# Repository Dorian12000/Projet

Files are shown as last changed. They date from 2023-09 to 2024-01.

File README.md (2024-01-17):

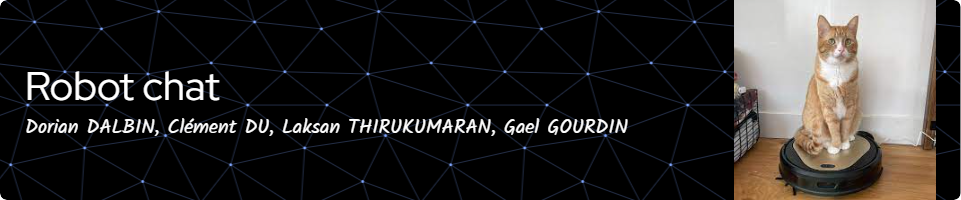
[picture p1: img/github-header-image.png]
robot chat


# Robot Chat et Souris

Ce projet consiste à créer un robot capable de jouer au jeu du chat et de la souris. Le robot est équipé de plusieurs fonctionnalités clés, notamment le contrôle de mouvement à l'aide de moteurs à courant continu (MCC), la localisation avec un Lidar YD X4, la détection du vide à l'aide de capteurs de bordure et le changement d'état ( Souris , Chat) grâce aux bumpers. 

## Schéma Fonctionnel : 
https://miro.com/app/dashboard/
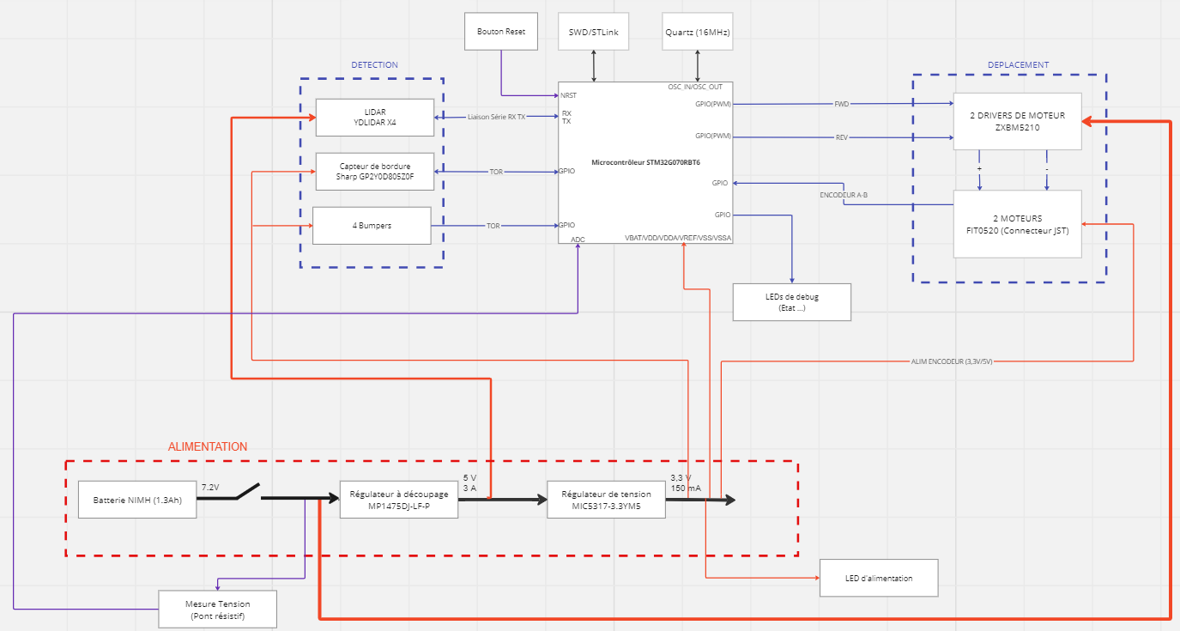
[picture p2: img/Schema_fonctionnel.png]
schéma fonctionnel


## Fonctionnalités principales

1. **Contrôle de Mouvement (MCC) :**
   - Le robot est capable de se déplacer dans son environnement grâce à des moteurs à courant continu. 
2. **Localisation avec Lidar X4 :**
   - Utilisation du Lidar X4 pour permettre au robot de s'orienter et de se repérer dans son environnement.

3. **Détection du Vide avec Capteurs de Bordure et Changement d'état :**
   - Les capteurs de bordure sont utilisés pour détecter les zones sans sol, afin d'empêcher le robot de tomber.
   - Changement d'états (Souris, Chat) grâce aux bumpers : Utilisation de  bumpers placés sur chaque côté du robot. Lorsqu'un des bumpers est touché, on change  l'état du robot. 

## Utilisation

1. **Exécution du Programme :**
   - Pour démarrer le robot, exécutez le programme principal. Assurez-vous que toutes les dépendances sont installées et que le robot est correctement alimenté. Le robot démarre en mode Souris.

2. **Interface Utilisateur :**
   - Pour connaître les événements enregistrés par le robot, veuillez connecter une ST-link entre le robot et votre ordinateur, puis ouvrir une console (TeraTerm, Putty, ...) configurée en 115200 bauds.
   - Trois LEDs sont présentes sur le robot pour indiquer son état en temps réel :
        - Led verte :
        	- allumée : état chat
        	- éteinte : état souris
        - Led orange : changement d'état pour chaque détection de bordure.
        - Led rouge : le robot a rencontré un problème et doit être redémarré.

## Pilote Lidar pour système robotique

1. **Introduction :**

Le pilote Lidar consiste en l'intégration d'un lidar dans un système robotique tel que notre robot. Le lidar est utilisé pour la détection d'obstacles, la cartographie de l'environnement et la localisation des autres robots dans la zone d'opération. Ce document fournit des informations sur les fichiers principaux du projet, y compris les fichiers `drv_lidar.c`, `LidarTask.c`, et la création de la tâche Lidar.

2. **Contenu des fichiers :**

	#### `drv_lidar.c`

	Le fichier `drv_lidar.c` contient le code source pour le pilote du lidar. Il comprend les fonctionnalités suivantes :

	- **Initialisation du Lidar** : La fonction `LidarInit` initialise le lidar en configurant la communication UART, en créant un sémaphore pour la synchronisation des lectures UART, et en activant le l'échantillonage du lidar et son moteur.

	- **Communication UART** : Le fichier utilise la communication UART avec le mécanisme DMA pour une transmission et réception de données efficace et non bloquante.

	- **Commandes Lidar** : Les fonctions `LidarScanStart` et `LidarScanStop` envoient respectivement les commandes de démarrage et d'arrêt du scan au lidar.

	- **Traitement des données** : Les fonctions `getLidarScanData`, `checkCS` et `convertSample` sont responsables de la réception, de la vérification de la somme de contrôle et de la conversion des données de scan du lidar.

	- **Analyse des données Lidar** : La fonction `whereIsNearestRobot` analyse les données du lidar pour déterminer la position du robot le plus proche.

	- **Gestion des erreurs** : La fonction `LidarHealthStatus` permet d'obtenir le statut de santé du lidar et de gérer les erreurs éventuelles.

	- **Autres fonctionnalités** : Le fichier contient également des fonctions pour définir la vitesse du lidar, obtenir des informations sur le lidar et redémarrer le lidar.

	#### `LidarTask.c`

	Le fichier `LidarTask.c` contient la définition de la tâche Lidar. Il gère les états de la tâche, notamment l'initialisation du lidar, le scan, le traitement des données et le mode veille.

	- **États de la tâche** : Les états comprennent l'initialisation (`LIDAR_INIT`), le scan (`LIDAR_SCANNING`) et le mode veille (`LIDAR_STANDBY`).

	- **Initialisation** : La tâche commence par initialiser le lidar, récupérer des informations sur le lidar afin d'assurer son bon fonctionnement, puis passer à l'état de scan.

	- **Scan Lidar** : Dans cet état, la tâche démarre le scan du lidar, reçoit les données de scan, les traite et effectue des actions en fonction de l'état principal du système (CAT ou MOUSE).

	- **Mode veille** : Un état futur pour le mode veille est également prévu mais n'est pas encore implémenté.

	- **Gestion des erreurs** : En cas d'erreur lors du scan, la tâche passe à l'état d'erreur pour gérer la situation.

3. **Utilisation du code :**

	- **Création de la tâche Lidar** : La fonction `createLidarTask` dans `LidarTask.c` crée la tâche Lidar en utilisant FreeRTOS. Elle définit la profondeur de la pile et la priorité de la tâche.

	- **Configuration du Lidar** : Le fichier `drv_lidar.c` comprend des fonctions pour l'initialisation du lidar, la configuration de la vitesse du moteur, le démarrage et l'arrêt du scan, l'obtention d'informations, la récupération des données de scan, etc.

	- **Gestion des états** : La tâche Lidar gère différents états, tels que l'initialisation, le scan et la veille. Ces états sont définis dans `LidarTask.c` et peuvent être étendus selon les besoins.

	- **Analyse des données** : La fonction `whereIsNearestRobot` analyse les données du lidar pour déterminer la position du robot le plus proche. Cette fonction peut être adaptée en fonction des exigences spécifiques du projet.

4. **Remarques :**

	- Le pilote du lidar est conçu pour fonctionner avec FreeRTOS. Assurez-vous que votre projet est configuré pour utiliser FreeRTOS.

	- La communication avec le lidar utilise le DMA pour une transmission et une réception de données efficaces et non bloquantes via UART.

	- La fonction principale de la tâche Lidar est gérée par la fonction `lidarTask()`, qui comprend une machine d'états pour gérer les différents états du lidar.

	- La tâche Lidar s'exécute en boucle continue, surveillant et gérant l'état du dispositif lidar.

	- Des types de données personnalisés et des macros de journalisation sont définis dans `types.h` et `logger.h`, respectivement.

# Organisation des tâches 

Pour organiser nos tâches liées aux différentes fonctions du Lidar et des moteurs, nous avons crée une tache principale avec une priorité élevée ( code source dans mainTask.c). Cette tâche est divisé en plusieurs états :
   - Main Init : Initialisation des tâches de démarrage du Lidar, des moteurs et de l'asservissement.
   - ERROR : Gestion d'erreur
   - Mouse : Test de l'état avec une Led
   - CAT : Test de l'état avec une Led
( Pour l'état CAT/MOUSE, des notifications sont générées lorsque les bumpers sont appuyés)

Chaque état implique l'appels des tâches et des fonctions nécessaires. Un timer est configuré pour suivre l'état actuel du robot.

## Contrôle moteur et asservissement en vitesse

Les deux MCC sont controlés par des pwm et asservis en vitesse par un correcteur proportionnel dans une tâche.

1. **Driver de moteur :**

   Les fichiers `moteur_drv.c/.h` contiennent les fonctions permettant de commander la vitesse ainsi que les directions des moteurs et de générer les pwm en conséquence. Ils prévoient aussi le calcul de la vitesse des moteurs et la lecture des encodeurs.

2. **Conversion de la position visée en commande de vitesse pour les moteurs :**

   	Cette tâche reçoit une structure comprenant la position (angle et distance) à laquelle doit se rendre le robot. Ces données sont interprétées pour générer une commande (vitesse et sens de rotation) pour chaque moteur. La commande est ensuite utilisée pour l'asservissement en vitesse.

3. **Asservissement en vitesse :**

	La boucle d'asservissement en vitesse se fait toutes les 500 ms et comprend :

	- Récupération de la commande en vitesse en fonction de la position visée.
	- La lecture des encodeurs.
	- Le calcul de l'erreur entre la mesure et la commande en vitesse.
	- Le calcul de la nouvelle commande en vitesse par le correcteur proportionnel.
	- Transmission de la nouvelle commande de vitesse pour générer les pwm.

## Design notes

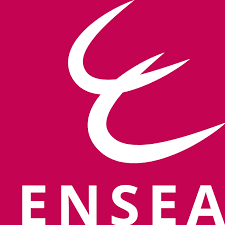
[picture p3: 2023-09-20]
img/ENSEA.png

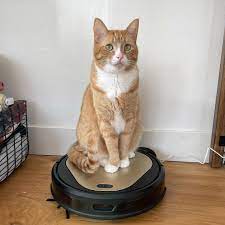
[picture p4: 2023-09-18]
img/chat.jpg

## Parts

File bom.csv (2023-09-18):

Composants | référence | quantité
microcontrolleur | STM32G070RBT6 | 1
Quartz 16 MHz | MCSJK-7U-16.00-10-30-80-B-30 | 1
Connecteur SWD/STLink | M50-3600742 | 1
Driver moteur | ZXBM5210-S | 2
Moteurs | DfRobot FIT0520 | 2
Régulateur 5V | AZ1117CH2-5.0TRG1 | 1
Régulateur 3,3V | MIC5317-3.3YM5 | 1
Batterie | NIMH 7.2V 1.3Ah | 1
Capteur bordure | Sharp GP2Y0D805Z0F | 2
Lidar | YDLIDAR X4 | 1
Connecteurs JST 2.54mm |  | 1
LED |  | 3
Intérrupteur |  | 1

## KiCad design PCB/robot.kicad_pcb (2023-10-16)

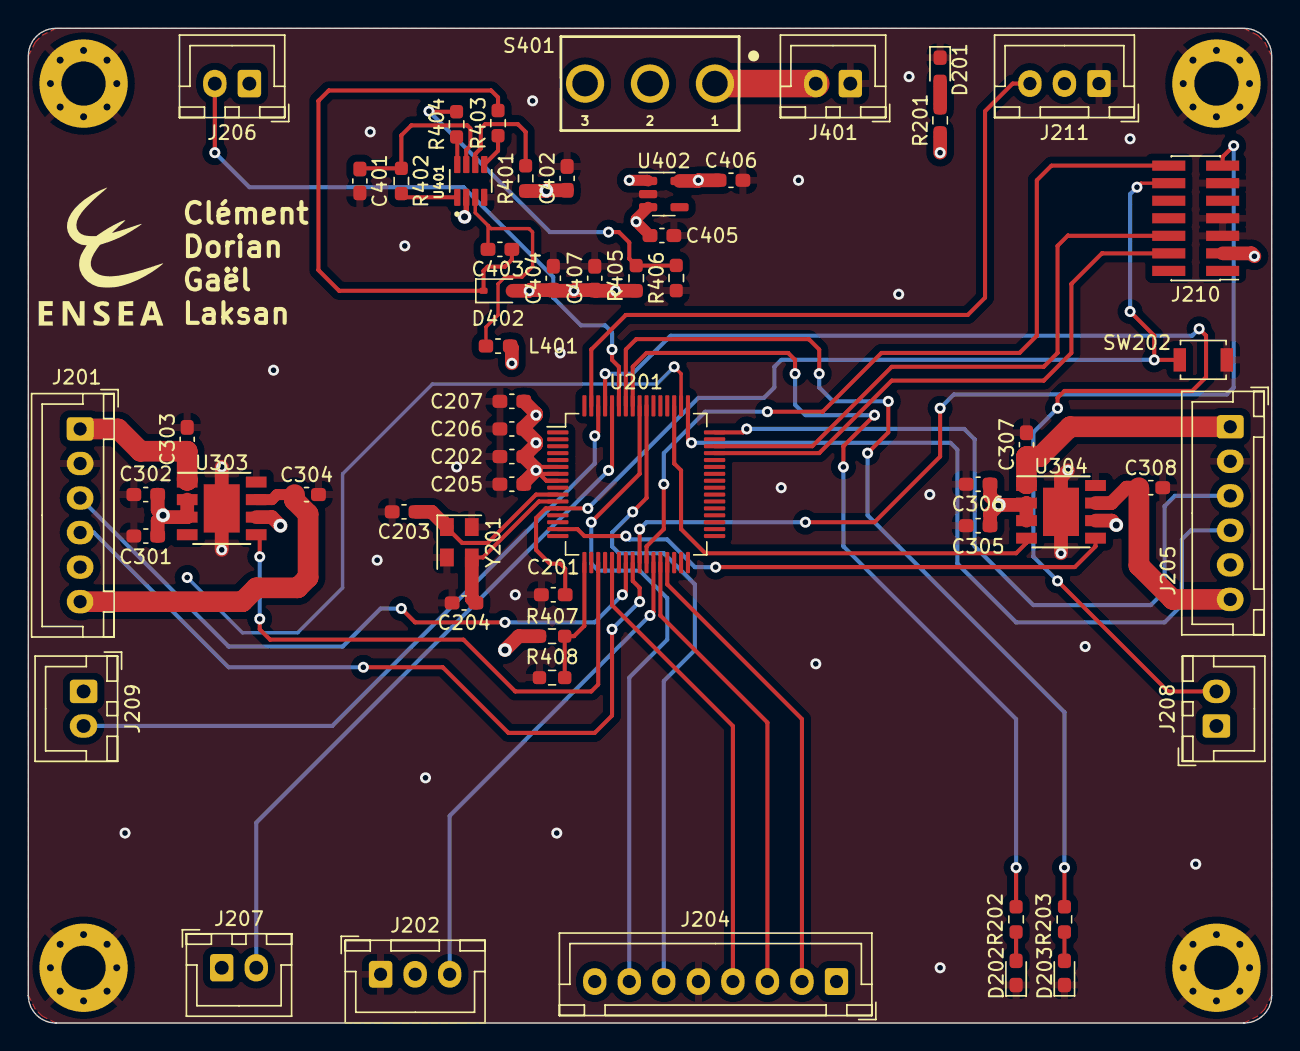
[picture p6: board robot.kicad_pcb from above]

Board: 4 copper layers, 90.0 x 72.0 mm, 61 parts (0 on the bottom side), 49 nets.

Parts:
C201, C202, C205, C206: 100nF; C_0603_1608Metric_Pad1.08x0.95mm_HandSolder
C203, C204: 10pF; C_0603_1608Metric_Pad1.08x0.95mm_HandSolder
C207: 4.7uF; C_0603_1608Metric_Pad1.08x0.95mm_HandSolder
C301, C305, C405, C406: 1uF; C_0603_1608Metric_Pad1.08x0.95mm_HandSolder
C302, C306: 10uF; C_0603_1608Metric_Pad1.08x0.95mm_HandSolder
C303, C304, C307, C308: 10nF; C_0603_1608Metric_Pad1.08x0.95mm_HandSolder
C401: 0.1uF; C_0603_1608Metric_Pad1.08x0.95mm_HandSolder
C402, C404, C407: 22uF; C_0603_1608Metric_Pad1.08x0.95mm_HandSolder
C403: 100n; C_0603_1608Metric_Pad1.08x0.95mm_HandSolder
D201: LED G; LED_0603_1608Metric_Pad1.05x0.95mm_HandSolder
D202: LED R; LED_0603_1608Metric_Pad1.05x0.95mm_HandSolder
D203: LED B; LED_0603_1608Metric_Pad1.05x0.95mm_HandSolder
D402: 1N4148WS; D_SOD-323
H201, H202, H203, H204: MountingHole_Pad; MountingHole_3.2mm_M3_Pad_Via
J201: Motor_L; JST_XH_B6B-XH-A_1x06_P2.50mm_Vertical
J202: bordure_R; JST_XH_B3B-XH-A_1x03_P2.50mm_Vertical
J204: LIDAR; JST_XH_B8B-XH-A_1x08_P2.50mm_Vertical
J205: Motor_R; JST_XH_B6B-XH-A_1x06_P2.50mm_Vertical
J206: BUMPER_F; JST_XH_B2B-XH-A_1x02_P2.50mm_Vertical
J207: BUMPER_B; JST_XH_B2B-XH-A_1x02_P2.50mm_Vertical
J208: BUMPER_R; JST_XH_B2B-XH-A_1x02_P2.50mm_Vertical
J209: BUMPER_L; JST_XH_B2B-XH-A_1x02_P2.50mm_Vertical
J210: Conn_02x07_Odd_Even; PinHeader_2x07_P1.27mm_Vertical_SMD
J211: bordure_F; JST_XH_B3B-XH-A_1x03_P2.50mm_Vertical
J401: Conn_BAT; JST_XH_B2B-XH-A_1x02_P2.50mm_Vertical
L401: 4.7uH; L_0603_1608Metric_Pad1.05x0.95mm_HandSolder
R201, R202, R203: 1k; R_0603_1608Metric_Pad0.98x0.95mm_HandSolder
R401, R402: 100k; R_0603_1608Metric_Pad0.98x0.95mm_HandSolder
R403: 20; R_0603_1608Metric_Pad0.98x0.95mm_HandSolder
R404: 16k; R_0603_1608Metric_Pad0.98x0.95mm_HandSolder
R405: 40.2k; R_0603_1608Metric_Pad0.98x0.95mm_HandSolder
R406: 13k; R_0603_1608Metric_Pad0.98x0.95mm_HandSolder
R407: 12k; R_0603_1608Metric_Pad0.98x0.95mm_HandSolder
R408: 10k; R_0603_1608Metric_Pad0.98x0.95mm_HandSolder
S401: 472121010111
SW202: SW_Push; SW_SPST_B3U-1000P
U201: STM32G070RBTx; LQFP-64_10x10mm_P0.5mm
U303, U304: ZXBM5210-SP; Diodes_SO-8EP
U401: MP1475DJ-LF-P
U402: MIC5317; SOT-23-5
Y201: 16M; Crystal_SMD_EuroQuartz_MT-4Pin_3.2x2.5mm

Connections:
7.2V: C301.2, C302.1, C305.2, C306.1, C402.1, R401.1, R407.1, S401.2, U303.2 (VM), U303.3 (VDD), U303.6 (VREF), U304.2 (VM), U304.3 (VDD), U304.6 (VREF), U401.2 (IN)
+3.3V: C202.1, C205.2, C206.2, C207.2, C406.1, J201.5, J202.2, J205.5, J206.1, J207.1, J208.1, J209.1, J210.3, J211.2, R201.1, U201.6 (VBAT), U201.7 (VREF+), U201.8 (VDD), U402.5 (VOUT)
+5V: C404.1, C405.1, C407.1, D402.2 (A), J204.8, L401.2, R405.2, U402.1 (VIN), U402.3 (~SHDN)
/Motor/FWD_ML: U201.50 (PD0), U303.4 (FWD)
/Motor/FWD_MR: U201.51 (PD1), U304.4 (FWD)
/Motor/M_L1: C303.1, J201.1, U303.1 (OUT1)
/Motor/M_L2: C304.1, J201.6, U303.7 (OUT2)
/Motor/M_R1: C307.1, J205.1, U304.1 (OUT1)
/Motor/M_R2: C308.1, J205.6, U304.7 (OUT2)
/Motor/REV_ML: U201.19 (PA2), U303.5 (REV)
/Motor/REV_MR: U201.15 (PC2), U304.5 (REV)
/Power/BAT_LVL: R407.2, R408.1, U201.17 (PA0)
/STM32/BUMPER_B: J207.2, U201.60 (PB6)
/STM32/BUMPER_F: J206.2, U201.59 (PB5)
/STM32/BUMPER_L: J209.2, U201.62 (PB8)
/STM32/BUMPER_R: J208.2, U201.61 (PB7)
/STM32/DEV_EN: J204.3, U201.28 (PB1)
/STM32/Endoder_LA: J201.3, U201.23 (PA6)
/STM32/Endoder_LB: J201.4, U201.24 (PA7)
/STM32/Endoder_RA: J205.4, U201.49 (PC9)
/STM32/Endoder_RB: J205.3, U201.48 (PC8)
/STM32/LED_B: R203.1, U201.58 (PB4)
/STM32/LED_R: R202.1, U201.57 (PB3)
/STM32/LIDAR_RX: J204.6, U201.55 (PD5)
/STM32/LIDAR_TX: J204.7, U201.56 (PD6)
/STM32/M_EN: J204.2, U201.29 (PB2)
/STM32/M_SCTR: J204.4, U201.21 (PA4)
/STM32/NRST: C201.1, J210.12, SW202.2, U201.12 (NRST)
/STM32/OSC_IN: C203.1, U201.10 (PF0), Y201.1
/STM32/SWCLK: J210.6, U201.46 (PA14)
/STM32/SWDIO: J210.4, U201.45 (PA13)
/STM32/VCP_RX: J210.14, U201.26 (PC5)
/STM32/VCP_TX: J210.13, U201.25 (PC4)
/STM32/V_BORDURE_F: J211.3, U201.63 (PB9)
/STM32/V_BORDURE_R: J202.3, U201.27 (PB0)
GND: C201.2, C202.2, C203.2, C204.2, C205.1, C206.1, C207.1, C301.1, C302.2, C303.2, C304.2, C305.1, C306.2, C307.2, C308.2, C401.2, C402.2, C404.2, C405.2, C406.2, C407.2, D201.1 (K), D202.1 (K), D203.1 (K), H201.1, H202.1, H203.1, H204.1, J201.2, J202.1, J204.5, J205.2, J210.5, J210.7, J210.11, J211.1, J401.1, R406.1, R408.2, SW202.1, U201.9 (VSS), U303.8 (GND), U303.9 (GND), U304.8 (GND), U304.9 (GND), U401.4 (GND), U402.2 (GND), Y201.2, Y201.4
unnamed: D201.2 (A), R201.2
unnamed: D202.2 (A), R202.2
unnamed: D203.2 (A), R203.2
unnamed: C403.1, D402.1 (K), R403.2
unnamed: J401.2, S401.1
unnamed: R404.2, R405.1, R406.2
unnamed: C204.1, U201.11 (PF1), Y201.3
unnamed: R403.1, U401.5 (BST)
unnamed: R401.2, U401.6 (EN/SYNC)
unnamed: R404.1, U401.8 (FB)
unnamed: R402.2, U401.1 (PG)
unnamed: C403.2, L401.1, U401.3 (SW)
unnamed: C401.1, R402.1, U401.7 (VCC)

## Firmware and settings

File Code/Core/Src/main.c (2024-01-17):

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
/* Includes ------------------------------------------------------------------*/
#include "main.h"
#include "cmsis_os.h"
#include "dma.h"
#include "tim.h"
#include "usart.h"
#include "gpio.h"

/* USER CODE BEGIN Includes */
#include <stdio.h>

#include "logger.h"
#include "types.h"
#include "mainTask.h"
#include "pid.h"
#include "pwm.h"
#include "motor_drv.h"
/* USER CODE END Includes */


/* USER CODE BEGIN PV */
// PWM MOTORS
PWM pwm_rev_left  = {.timer = &htim16, .channel = TIM_CHANNEL_1};
PWM pwm_fwd_left  = {.timer = &htim17, .channel = TIM_CHANNEL_1};
PWM pwm_rev_right = {.timer = &htim15, .channel = TIM_CHANNEL_1};
PWM pwm_fwd_right = {.timer = &htim15, .channel = TIM_CHANNEL_2};
// PWM LIDAR
PWM pwm_lidar     = {.timer = &htim14, .channel = TIM_CHANNEL_1};

/* USER CODE END PV */

void SystemClock_Config(void);
void MX_FREERTOS_Init(void);
/* USER CODE BEGIN 0 */
int __io_putchar(int chr)
{
	HAL_UART_Transmit(&huart2, (uint8_t*)&chr, 1, HAL_MAX_DELAY);
	return chr;
}
/* USER CODE END 0 */

/**
  * @brief  The application entry point.
  * @retval int
  */
int main(void)
{
  /* MCU Configuration--------------------------------------------------------*/

  /* Reset of all peripherals, Initializes the Flash interface and the Systick. */
  HAL_Init();

  /* Configure the system clock */
  SystemClock_Config();

  /* Initialize all configured peripherals */
  MX_GPIO_Init();
  MX_DMA_Init();
  MX_TIM1_Init();
  MX_TIM3_Init();
  MX_TIM14_Init();
  MX_TIM15_Init();
  MX_TIM16_Init();
  MX_TIM17_Init();
  MX_USART2_UART_Init();
  MX_USART4_UART_Init();
  /* USER CODE BEGIN 2 */
	printf("================== boot ================\n");

	// TIMER PWM LIDAR
	if(START_PWM(pwm_lidar) != HAL_OK)
	{
		printf("ERROR: PWM Start LIDAR\r\n");
		Error_Handler();
	}

	// TIMER PWM MOTORS
	if((START_PWM(pwm_rev_left) != HAL_OK) || (START_PWM(pwm_fwd_left) != HAL_OK) ||
			(START_PWM(pwm_rev_right) != HAL_OK) || (START_PWM(pwm_fwd_right) != HAL_OK))
	{
		printf("ERROR: PWM Start MOTORS\r\n");
		Error_Handler();
	}

	// TIMER ENCODEUR MOTORS
	if((HAL_TIM_Encoder_Start(&htim1, TIM_CHANNEL_ALL) != HAL_OK) ||
			(HAL_TIM_Encoder_Start(&htim3, TIM_CHANNEL_ALL) != HAL_OK))
	{
		printf("ERROR: ENCODEUR Start MOTORS\r\n");
		Error_Handler();
	}

	// PID struct init
	initPID(&pid_motor_left, 0.5, 0, 0, TE);
	initPID(&pid_motor_right, 0.5, 0, 0, TE);

	// Motor struct init
	initMotor(&motor_left, &pwm_fwd_left, &pwm_rev_left, &htim3);
	initMotor(&motor_right, &pwm_fwd_right, &pwm_rev_right, &htim1);

	//__HAL_TIM_SET_COMPARE(&htim14, TIM_CHANNEL_1 ,85);

	bool ret = createMainTask();

  /* USER CODE END 2 */

  /* Call init function for freertos objects (in freertos.c) */
  MX_FREERTOS_Init();

  /* Start scheduler */
  osKernelStart();

  /* We should never get here as control is now taken by the scheduler */
  /* Infinite loop */
  /* USER CODE BEGIN WHILE */
  

  while (1)
  {

    /* USER CODE END WHILE */

    /* USER CODE BEGIN 3 */
  }
  /* USER CODE END 3 */
}

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
/**
  * @brief  Period elapsed callback in non blocking mode
  * @note   This function is called  when TIM6 interrupt took place, inside
  * HAL_TIM_IRQHandler(). It makes a direct call to HAL_IncTick() to increment
  * a global variable "uwTick" used as application time base.
  * @param  htim : TIM handle
  * @retval None
  */
void HAL_TIM_PeriodElapsedCallback(TIM_HandleTypeDef *htim)
{
  if (htim->Instance == TIM6) {
    HAL_IncTick();
  }
}

/**
  * @brief  This function is executed in case of error occurrence.
  * @retval None
  */
void Error_Handler(void)
{
  /* USER CODE BEGIN Error_Handler_Debug */
  /* User can add his own implementation to report the HAL error return state */
  __disable_irq();
  while (1)
  {
  }
  /* USER CODE END Error_Handler_Debug */
}

#ifdef  USE_FULL_ASSERT
/**
  * @brief  Reports the name of the source file and the source line number
  *         where the assert_param error has occurred.
  * @param  file: pointer to the source file name
  * @param  line: assert_param error line source number
  * @retval None
  */
void assert_failed(uint8_t *file, uint32_t line)
{
  /* USER CODE BEGIN 6 */
  /* User can add his own implementation to report the file name and line number,
     ex: printf("Wrong parameters value: file %s on line %d\r\n", file, line) */
  /* USER CODE END 6 */
}
#endif /* USE_FULL_ASSERT */

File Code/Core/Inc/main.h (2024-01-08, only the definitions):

#define LIDAR_M_EN_Pin GPIO_PIN_4
#define LIDAR_M_EN_GPIO_Port GPIOC
#define LIDAR_DEV_EN_Pin GPIO_PIN_5
#define LIDAR_DEV_EN_GPIO_Port GPIOC
#define LIDAR_M_SCTR_Pin GPIO_PIN_1
#define LIDAR_M_SCTR_GPIO_Port GPIOB
#define LED_RED_Pin GPIO_PIN_11
#define LED_RED_GPIO_Port GPIOB
#define LED_ORANGE_Pin GPIO_PIN_12
#define LED_ORANGE_GPIO_Port GPIOB
#define LED_GREEN_Pin GPIO_PIN_13
#define LED_GREEN_GPIO_Port GPIOB
#define MR_REV_Pin GPIO_PIN_14
#define MR_REV_GPIO_Port GPIOB
#define MR_FWD_Pin GPIO_PIN_15
#define MR_FWD_GPIO_Port GPIOB
#define MR_ENC_B_Pin GPIO_PIN_8
#define MR_ENC_B_GPIO_Port GPIOA
#define MR_ENC_A_Pin GPIO_PIN_9
#define MR_ENC_A_GPIO_Port GPIOA
#define ML_ENC_B_Pin GPIO_PIN_6
#define ML_ENC_B_GPIO_Port GPIOC
#define ML_ENC_A_Pin GPIO_PIN_7
#define ML_ENC_A_GPIO_Port GPIOC
#define ML_REV_Pin GPIO_PIN_0
#define ML_REV_GPIO_Port GPIOD
#define ML_FWD_Pin GPIO_PIN_1
#define ML_FWD_GPIO_Port GPIOD
#define BORDER_BACK_Pin GPIO_PIN_2
#define BORDER_BACK_GPIO_Port GPIOD
#define BORDER_BACK_EXTI_IRQn EXTI2_3_IRQn
#define BORDER_FRONT_Pin GPIO_PIN_3
#define BORDER_FRONT_GPIO_Port GPIOD
#define BORDER_FRONT_EXTI_IRQn EXTI2_3_IRQn
#define PC_TX_Pin GPIO_PIN_5
#define PC_TX_GPIO_Port GPIOD
#define PC_RX_Pin GPIO_PIN_6
#define PC_RX_GPIO_Port GPIOD
#define BUMPER_L_Pin GPIO_PIN_6
#define BUMPER_L_GPIO_Port GPIOB
#define BUMPER_R_Pin GPIO_PIN_7
#define BUMPER_R_GPIO_Port GPIOB
#define BUMPER_B_Pin GPIO_PIN_8
#define BUMPER_B_GPIO_Port GPIOB
#define BUMPER_F_Pin GPIO_PIN_9
#define BUMPER_F_GPIO_Port GPIOB

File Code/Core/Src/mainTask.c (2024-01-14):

/**
 *     _______    _____     __     ______    _______        ____
 *    |   ____|  |     \   |  |   / _____)  |   ____|      /    \
 *    |  |__     |  |\  \  |  |  ( (____    |  |__        /  /\  \
 *    |   __|    |  | \  \ |  |   \____ \   |   __|      /  ____  \
 *    |  |____   |  |  \  \|  |   _____) )  |  |____    /  /    \  \
 *    |_______|  |__|   \_____|  (______/   |_______|  /__/      \__\
 *
 * @file    mainTask.c
 * @Author  Dorian Dalbin, Clement Du, Laksan Thirukumaran, Gael Gourdin
 * @Created	2023-10-28
 * @brief
 *
 **/

#include "mainTask.h"

#include "main.h"
#include "cmsis_os.h"
#include "logger.h"
#include "types.h"
#include <limits.h>
#include "lidarTask.h"
#include "task_motor.h"

#define TASK_MAIN_STACK_DEPTH 512
#define TASK_MAIN_PRIORITY 99

typedef struct {
	mainState_t state;
	mainState_t lastState;
	TimerHandle_t timer;
}mainHandle_t;

TaskHandle_t h_task_main;
mainHandle_t mainHandle;

void HAL_GPIO_EXTI_Rising_Callback(uint16_t GPIO_Pin) {
	LOG_MAIN_ENTER();
	BaseType_t xHigherPriorityTaskWoken = pdFALSE;
	if(GPIO_Pin == BUMPER_F_Pin) {
		xTaskNotifyFromISR(h_task_main, BUMPER_F_NOTIFY, eSetBits, &xHigherPriorityTaskWoken);
	} else if(GPIO_Pin == BUMPER_B_Pin) {
		xTaskNotifyFromISR(h_task_main, BUMPER_B_NOTIFY, eSetBits, &xHigherPriorityTaskWoken );
	} else if(GPIO_Pin == BUMPER_R_Pin) {
		xTaskNotifyFromISR(h_task_main, BUMPER_R_NOTIFY, eSetBits, &xHigherPriorityTaskWoken );
	} else if(GPIO_Pin == BUMPER_L_Pin) {
		xTaskNotifyFromISR(h_task_main, BUMPER_L_NOTIFY, eSetBits, &xHigherPriorityTaskWoken );
	} else if(GPIO_Pin == BORDER_FRONT_Pin) {
		HAL_GPIO_TogglePin(LED_ORANGE_GPIO_Port, LED_ORANGE_Pin);
		xTaskNotifyFromISR(getPositionMotorTaskHandle(), BORDER_F_NOTIFY, eSetBits, &xHigherPriorityTaskWoken );
	} else if(GPIO_Pin == BORDER_BACK_Pin) {
		HAL_GPIO_TogglePin(LED_ORANGE_GPIO_Port, LED_ORANGE_Pin);
		xTaskNotifyFromISR(getPositionMotorTaskHandle(), BORDER_B_NOTIFY, eSetBits, &xHigherPriorityTaskWoken );
	}
	portYIELD_FROM_ISR( xHigherPriorityTaskWoken );
}

/**
 * @brief Gets the current state of the main system.
 *
 * This function retrieves and returns the current state of the main system.
 *
 * @return The current state of the main system.
 */
mainState_t getMainState(void) {
	return mainHandle.state;
}

/**
 * @brief Toggles the main system state between CAT and MOUSE.
 *
 * This function toggles the main system state between CAT and MOUSE. If the
 * current state is CAT, it switches to MOUSE, and vice versa.
 */
void setMainState(void) {
	if(mainHandle.state == MAIN_CAT) {
		mainHandle.state = MAIN_MOUSE;
	} else if(mainHandle.state == MAIN_MOUSE) {
		mainHandle.state = MAIN_CAT;
	}
}

/**
 * @brief Main task that controls the overall system behavior.
 *
 * This task is responsible for managing the overall behavior of the system.
 * It transitions between different states and performs actions based on the
 * current state. Additionally, it toggles LEDs, processes notifications, and
 * handles timeouts using a timer.
 */
void mainTask(void *param) {
	returncode_t status;
	uint32_t ulNotifiedValue;

	mainHandle.state = MAIN_INIT;
	mainHandle.lastState = mainHandle.state;
	mainHandle.timer = xTimerCreate("Main Timer", 100, pdTRUE, NULL, NULL);

	while(1) {
		switch (mainHandle.state) {
			case MAIN_INIT: {
				if(xTimerIsTimerActive(mainHandle.timer) == pdFALSE) {
					xTimerStart(mainHandle.timer, 0);
					positionMotorTaskCreate();
					asservMotorTaskCreate();
					createLidarTask();
				}
				mainHandle.state = MAIN_MOUSE;
				break;
			}
			case MAIN_CAT: {
				if(xTimerIsTimerActive(mainHandle.timer) == pdFALSE) {
					xTimerStart(mainHandle.timer, 0);
					HAL_GPIO_WritePin(LED_GREEN_GPIO_Port, LED_GREEN_Pin, GPIO_PIN_SET);
				}
				break;
			}
			case MAIN_MOUSE: {
				if(xTimerIsTimerActive(mainHandle.timer) == pdFALSE) {
					xTimerStart(mainHandle.timer, 0);
					HAL_GPIO_WritePin(LED_GREEN_GPIO_Port, LED_GREEN_Pin, GPIO_PIN_RESET);
				}
				break;
			}
			case MAIN_ERROR : {
				if(xTimerIsTimerActive(mainHandle.timer) == pdFALSE) {
					xTimerStart(mainHandle.timer, 0);
					
				}
				break;
			}
			default:
				mainHandle.state = MAIN_INIT;
				break;
		}
		if(mainHandle.lastState != mainHandle.state) {
			xTimerStop(mainHandle.timer, 0);
			mainHandle.lastState = mainHandle.state;
		}
		if(xTaskNotifyWait(0, ULONG_MAX, &ulNotifiedValue, 5000) == pdTRUE) {
			setMainState();
//			HAL_GPIO_TogglePin(LED_B_GPIO_Port, LED_B_Pin);
//			HAL_GPIO_TogglePin(LED_R_GPIO_Port, LED_R_Pin);
			//xTaskNotify(lidarHandle, &ulNotifiedValue, eSetBits); //TODO notify side that has beed affected
			taskENTER_CRITICAL();
			vTaskDelay(2000);
			taskEXIT_CRITICAL();
		}
		//vTaskDelay(1);
	}
}

/**
 * @brief Creates and initializes the main task.
 *
 * This function creates and initializes the main task, which is responsible
 * for managing the overall behavior of the system.
 *
 * @return Returns true if the task creation is successful; otherwise, returns false.
 */
uint8_t createMainTask(void) {
	if (xTaskCreate(mainTask, "Main", TASK_MAIN_STACK_DEPTH, NULL, TASK_MAIN_PRIORITY, &h_task_main) != pdPASS) {
		LOG_RTOS_ERROR("Error creating task Main");
		return false;
	}
	else {
		LOG_RTOS_INFO(COLOR_GREEN"Main task create");
		return true;
	}
}

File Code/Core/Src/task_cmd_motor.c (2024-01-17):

/*
 * task_motor.c
 *
 *  Created on: Dec 19, 2023
 *      Author: gourd
 */

#include "task_motor.h"
#include "mainTask.h"
#include "drv_lidar.h"
#include "FreeRTOS.h"
#include "main.h"
#include <stdio.h>
#include <limits.h>

#define STACK_SIZE_POSITION_MOTOR 1000
#define TASK_PRIORITY_POSITION_MOTOR 90


command_t command_motor_left;
command_t command_motor_right;

TaskHandle_t position_motor_task_h = NULL;

/**
 * @brief Crée la tâche de positionnement moteur.
 *
 * Cette fonction crée une tâche de positionnement moteur avec les paramètres spécifiés
 * dans les macros correspondantes.
 *
 * @note Assurez-vous que les macros STACK_SIZE_POSITION_MOTOR et TASK_PRIORITY_POSITION_MOTOR
 *       sont définies avec les valeurs appropriées avant d'appeler cette fonction.
 *
 * @see vTaskPositionMotor, STACK_SIZE_POSITION_MOTOR, TASK_PRIORITY_POSITION_MOTOR
 */
void positionMotorTaskCreate(void)
{
    if (xTaskCreate(vTaskPositionMotor, "Position Motor Task", STACK_SIZE_POSITION_MOTOR, NULL, TASK_PRIORITY_POSITION_MOTOR, &position_motor_task_h) != pdPASS)
    {
        printf("Error position motor task create\r\n");
        Error_Handler();
    }
}


/**
 * @brief Obtient la poignée de la tâche de positionnement moteur.
 *
 * Cette fonction renvoie la poignée (handle) de la tâche de positionnement moteur,
 * permettant ainsi d'accéder à la tâche depuis d'autres parties du programme.
 *
 * @return La poignée (handle) de la tâche de positionnement moteur.
 */
TaskHandle_t getPositionMotorTaskHandle(void)
{
    return position_motor_task_h;
}


/**
 * @brief Tâche de positionnement moteur.
 *
 * Cette tâche gère le positionnement du moteur en réagissant aux notifications reçues.
 * Elle interprète les notifications des capteurs de bordure et de la position Lidar,
 * puis ajuste les commandes des moteurs en conséquence.
 *
 * @param param Pointeur vers les paramètres de la tâche (non utilisé ici).
 */
void vTaskPositionMotor(void *param)
{
    uint32_t notify_value;
    position_t position_to_go = {19.0, 10};

    for (;;)
    {
        if (xTaskNotifyWait(0, ULONG_MAX, &notify_value, portMAX_DELAY) == pdTRUE)
        {
            if (notify_value == BORDER_F_NOTIFY) // Notification ISR capteurs bordure
            {
                // Gauche stop, Droit stop
                command_motor_left.speed = 0;
                command_motor_left.dir   = STOP;
                command_motor_right.speed = 0;
                command_motor_right.dir  = STOP;
            }
            else // Nouvelle notification de position
            {
                // TODO: Choper la structure position_t du Lidar

                float angle = position_to_go.angle;
                uint16_t distance = position_to_go.distance;

                // Gestion du positionnement en angle en priorité
                if (angle != 0 || angle != 180)
                {
                    // Met à jour les états et la vitesse de chaque moteur en fonction de l'angle
                    angleToCommand(angle);
                }
                // Vers la direction en ligne droite une fois que le robot est orienté correctement
                else if (distance > 0)
                {
                    // Met à jour les états et la vitesse de chaque moteur en fonction de la distance
                    distanceToCommand(distance, angle);
                }
            }
        }
    }
}


/**
 * @brief Convertit un angle en commandes moteur.
 *
 * Cette fonction convertit un angle en commandes moteur pour orienter le robot
 * dans la direction spécifiée. Elle ajuste les vitesses et directions des moteurs
 * en fonction des quadrants de l'angle.
 *
 * @param angle Angle de rotation du robot.
 */
void angleToCommand(float angle)
{
    if (angle > 0 && angle <= 90)
    {
        // Gauche en avant, Droit moins vite
        command_motor_left.speed  = 100;
        command_motor_left.dir    = FWD;
        command_motor_right.speed = 20;
        command_motor_right.dir   = FWD;
    }
    else if (angle > 90 && angle <= 180)
    {
        // Gauche en arrière, Droit moins vite
        command_motor_left.speed  = 100;
        command_motor_left.dir    = REV;
        command_motor_right.speed = 20;
        command_motor_right.dir   = REV;
    }
    else if (angle > 180 && angle <= 270)
    {
        // Gauche moins vite, Droit en arrière
        command_motor_left.speed  = 20;
        command_motor_left.dir    = REV;
        command_motor_right.speed = 100;
        command_motor_right.dir   = REV;
    }
    else
    {
        // Gauche moins vite, Droit en avant
        command_motor_left.speed  = 20;
        command_motor_left.dir    = FWD;
        command_motor_right.speed = 100;
        command_motor_right.dir   = FWD;
    }
}


/**
 * @brief Convertit une distance en commandes moteur pour une trajectoire en ligne droite.
 *
 * Cette fonction convertit une distance en commandes moteur pour déplacer le robot
 * dans une trajectoire en ligne droite. Elle ajuste les vitesses et directions des moteurs
 * en fonction de l'angle spécifié (0 ou 180 degrés).
 *
 * @param distance Distance à parcourir en ligne droite.
 * @param angle    Angle de la trajectoire (0 ou 180 degrés).
 */
void distanceToCommand(uint16_t distance, float angle)
{
    if (angle == 180)
    {
        // Gauche en arrière, Droit en arrière
        command_motor_left.speed  = 100;
        command_motor_left.dir    = REV;
        command_motor_right.speed = 100;
        command_motor_right.dir   = REV;
    }
    else if (angle == 0)
    {
        // Gauche en avant, Droit en avant
        command_motor_left.speed  = 100;
        command_motor_left.dir    = FWD;
        command_motor_right.speed = 100;
        command_motor_right.dir   = FWD;
    }
}

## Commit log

2023-09-18 add: bom
2023-09-18 chore: bom
    [bom.csv]
2023-09-18 chore: remove line
    [bom.csv]
2023-09-18 chore: capteur de bordure
    [bom.csv]
2023-09-18 chore: reg 5V
2023-09-18 chore: add led on bom
    [bom.csv]
2023-09-18 add: kicad project
    [robot.kicad_pcb, robot.kicad_sch]
2023-09-19 add: shematic
    [STM32.kicad_sch, motor.kicad_sch, power.kicad_sch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]
2023-09-19 chore: pcb
    [STM32.kicad_sch, motor.kicad_sch, power.kicad_sch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]
2023-09-19 chore: ignore PCB folder
2023-09-19 chore: pcb batterie lvl
2023-09-20 update kicad
2023-09-21 chore: update pcb
2023-09-21 chore: mounting via pcb
2023-09-21 add: lidar dev manual
2023-09-25 chore: schematic review
2023-09-25 update: schematic
2023-10-02 update: pcb
2023-10-05 pwm files
2023-10-09 gitignore update
    [STM32.kicad_sch, motor.kicad_sch, power.kicad_sch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]
2023-12-18 chore: interrupt
2023-12-18 add: lidar file
2023-12-20 nouveau pin
2023-12-20 Meilleure organisation parce que Dorianne a fait de la merde
2024-01-08 fix: lidar config
2024-01-14 chore: quelques modif de code
2024-01-14 chore: lidar documentation

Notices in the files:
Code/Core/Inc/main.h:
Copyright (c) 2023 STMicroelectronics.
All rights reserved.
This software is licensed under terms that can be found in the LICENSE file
